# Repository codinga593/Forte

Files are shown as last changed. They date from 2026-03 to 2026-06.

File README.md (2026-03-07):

FORTE is a mid powered rocket with an estimated flight alitude of 137m initially, and a planned 1000m flight on a high powered motor later. 
It features a miniature onboard flight computer to verify data logging and live telemetry capabilties. 
The Flight computer has an inertial measurement unit and barometer to sense it's height and orientation. A LoRa Chip is placed onboard to stream data over 915 mHz to a ground station. 

The PCB is mainly for telemetry and datalogging, running custom firmware to achieve this. To get the PCB, you can send the gerber files to your manufacturer of choice, and buy components from online services such as LCSC, digikey or mouser. The rocket kit is available from LOC Precision and costs about $90.

This Rocket is my next step in my rocketry journey, allowing me to explore telemetry onboard rockets, efficient datalogging and building up to something more complex such as active control.

Render of Final PCB
Screenshot 2026-03-08 at 9 48 38 am

Model of Rocket
Screenshot 2026-03-08 at 9 41 17 am

Avionics Bay CAD
Screenshot 2026-03-08 at 9 33 35 am

## Bill of Materials (BOM)

| Designator | Part Name | Qty | Value / Part Number | Link |
|---|---|---|---|---|
| C14, C15, C16, C17, C18, C27, C28, C29, C30, C31, C35, C36 | Capacitor | 12 | 100 nF 0603 | https://www.digikey.com/en/products/detail/murata-electronics/GRM188R71C104KA01D |
| C13, C20, C21 | Capacitor | 3 | 1 µF 0603 | https://www.digikey.com/en/products/detail/murata-electronics/GRM188R61A105KA61D |
| C24, C25 | Capacitor | 2 | 2.2 µF 0603 | https://www.digikey.com/en/products/detail/murata-electronics/GRM188R61A225KE15 |
| C22, C23 | Capacitor | 2 | 10 pF 0603 | https://www.digikey.com/en/products/detail/murata-electronics/GRM1885C1H100JA01D |
| C34 | Capacitor | 1 | 22 µF 0603 | https://www.digikey.com/en/products/detail/murata-electronics/GRM188R60J226MEA0 |
| C26, C38, C39 | Capacitor | 3 | 100 nF 0603 | https://www.digikey.com/en/products/detail/murata-electronics/GRM188R71C104KA01D |
| R2, R3, R4, R8, R9, R10, R11, R12, R13, R14, R15, R18 | Resistor | 12 | 10 kΩ 0603 | https://www.digikey.com/en/products/detail/yageo/RC0603FR-0710KL |
| R16, R17 | Resistor | 2 | 0603 220Ω | https://www.digikey.com/en/products/detail/yageo/RC0603FR |
| U3 | Microcontroller | 1 | STM32F405RGT6 | https://www.digikey.com/en/products/detail/stmicroelectronics/STM32F405RGT6 |
| IC1 | SPI Flash Memory | 1 | W25Q128JVFIQ | https://www.digikey.com/en/products/detail/winbond-electronics/W25Q128JVFIQ |
| U2 | Barometric Pressure Sensor | 1 | MS5611-01BA | https://www.digikey.com/en/products/detail/te-connectivity/MS5611-01BA |
| U4 | GNSS Receiver | 1 | u-blox MAX-M10S | https://www.digikey.com/en/products/detail/u-blox/MAX-M10S-00B |
| U5 | USB ESD Protection | 1 | USBLC6-2SC6 | https://www.digikey.com/en/products/detail/stmicroelectronics/USBLC6-2SC6 |
| U13 | Buck Converter | 1 | TPS54525PWPR | https://www.digikey.com/en/products/detail/texas-instruments/TPS54525PWPR |
| Y2 | Crystal | 1 | 16 MHz SMD | https://www.digikey.com/en/products/detail/ecs-inc/ECS-160-20-33Q |
| J2 | RF Connector | 1 | U.FL-R-SMT-01 | https://www.digikey.com/en/products/detail/hirose-electric/U-FL-R-SMT-01 |
| J4 | USB-C Connector | 1 | USB4105-GF-A | https://www.digikey.com/en/products/detail/gct/USB4105-GF-A |
| TP1, TP2 | Test Point | 2 | PCB Test Pad | https://www.digikey.com/en/products/detail/keystone-electronics/5015 |
| SW2 | Slide Switch | 1 | SPDT (PCM12 style) | https://www.digikey.com/en/products/detail/c-k/PCM12SMTR |

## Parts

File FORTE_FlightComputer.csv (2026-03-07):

Id | Designator | Footprint | Quantity | Designation | Supplier and ref
1 | C27,C28,C16,C15,C18,C35,C17,C31,C14,C30,C36,C29 | C_0603_1608Metric | 12 | 100n
2 | IC1 | SOIC127P1032X264-16N | 1 | W25Q128JVFIQ
3 | J2 | HRS_U.FL-R-SMT_01_ | 1 | U.FL-R-SMT_01_
4 | R8,R3,R14,R10,R18,R9,R2,R15,R13,R4,R11,R12 | R_0603_1608Metric | 12 | 10k
5 | C20,C21,C13 | C_0603_1608Metric | 3 | 1u
6 | U5 | SOT-23-6 | 1 | USBLC6-2SC6
7 | C34 | C_0603_1608Metric | 1 | 22u
8 | C22,C23 | C_0603_1608Metric | 2 | 10pf
9 | U13 | PWP14_2P31X2P46_TEX | 1 | TPS54525PWPR
10 | U2 | LGA-8_3x5mm_P1.25mm | 1 | MS5611-01BA
11 | IC2 | 114993390 | 1 | 114993390
12 | R17,R16 | R_0603_1608Metric | 2 | R
13 | U4 | XCVR_MAX-M10S-00B | 1 | MAX-M10S-00B
14 | C24,C25 | C_0603_1608Metric | 2 | 2.2u
15 | Y2 | Crystal_SMD_3225-4Pin_3.2x2.5mm | 1 | 16Mhz
16 | U3 | LQFP-64_10x10mm_P0.5mm | 1 | STM32F405RGTx
17 | TP2,TP1 | TestPoint_Pad_1.5x1.5mm | 2 | TestPoint
18 | J4 | USB_C_Receptacle_GCT_USB4105-xx-A_16P_TopMnt_Horizontal | 1 | USB_C_Receptacle_USB2.0_16P
19 | C26,C39,C38 | C_0603_1608Metric | 3 | 100nf
20 | SW2 | SW_SPDT_PCM12 | 1 | SW_SPDT
21 | C19 | C_0603_1608Metric | 1 | 10n
22 | J5 | MOLEX_5025700893 | 1 | 5025700893
23 | J6 | AMASS_XT30PW-F_1x02_P2.50mm_Horizontal | 1 | Conn_01x02_Pin
24 | J3 | PinHeader_1x06_P2.54mm_Vertical | 1 | Conn_01x06_Pin
25 | C33 | C_0603_1608Metric | 1 | 10u
26 | U6 | XDCR_LSM6DSO32TR | 1 | LSM6DSO32TR
27 | L10 | WE-XHMA_6060 | 1 | 6.8 µH
28 | FB1 | FB_BLA31AG121SN4D | 1 | BLA31AG121SN4D
29 | R6,R7 | R_0603_1608Metric | 2 | 5k1
30 | C32 | C_0603_1608Metric | 1 | 10uF
31 | C37 | C_0603_1608Metric | 1 | 10uf

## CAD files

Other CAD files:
Avionics Bay.f3z

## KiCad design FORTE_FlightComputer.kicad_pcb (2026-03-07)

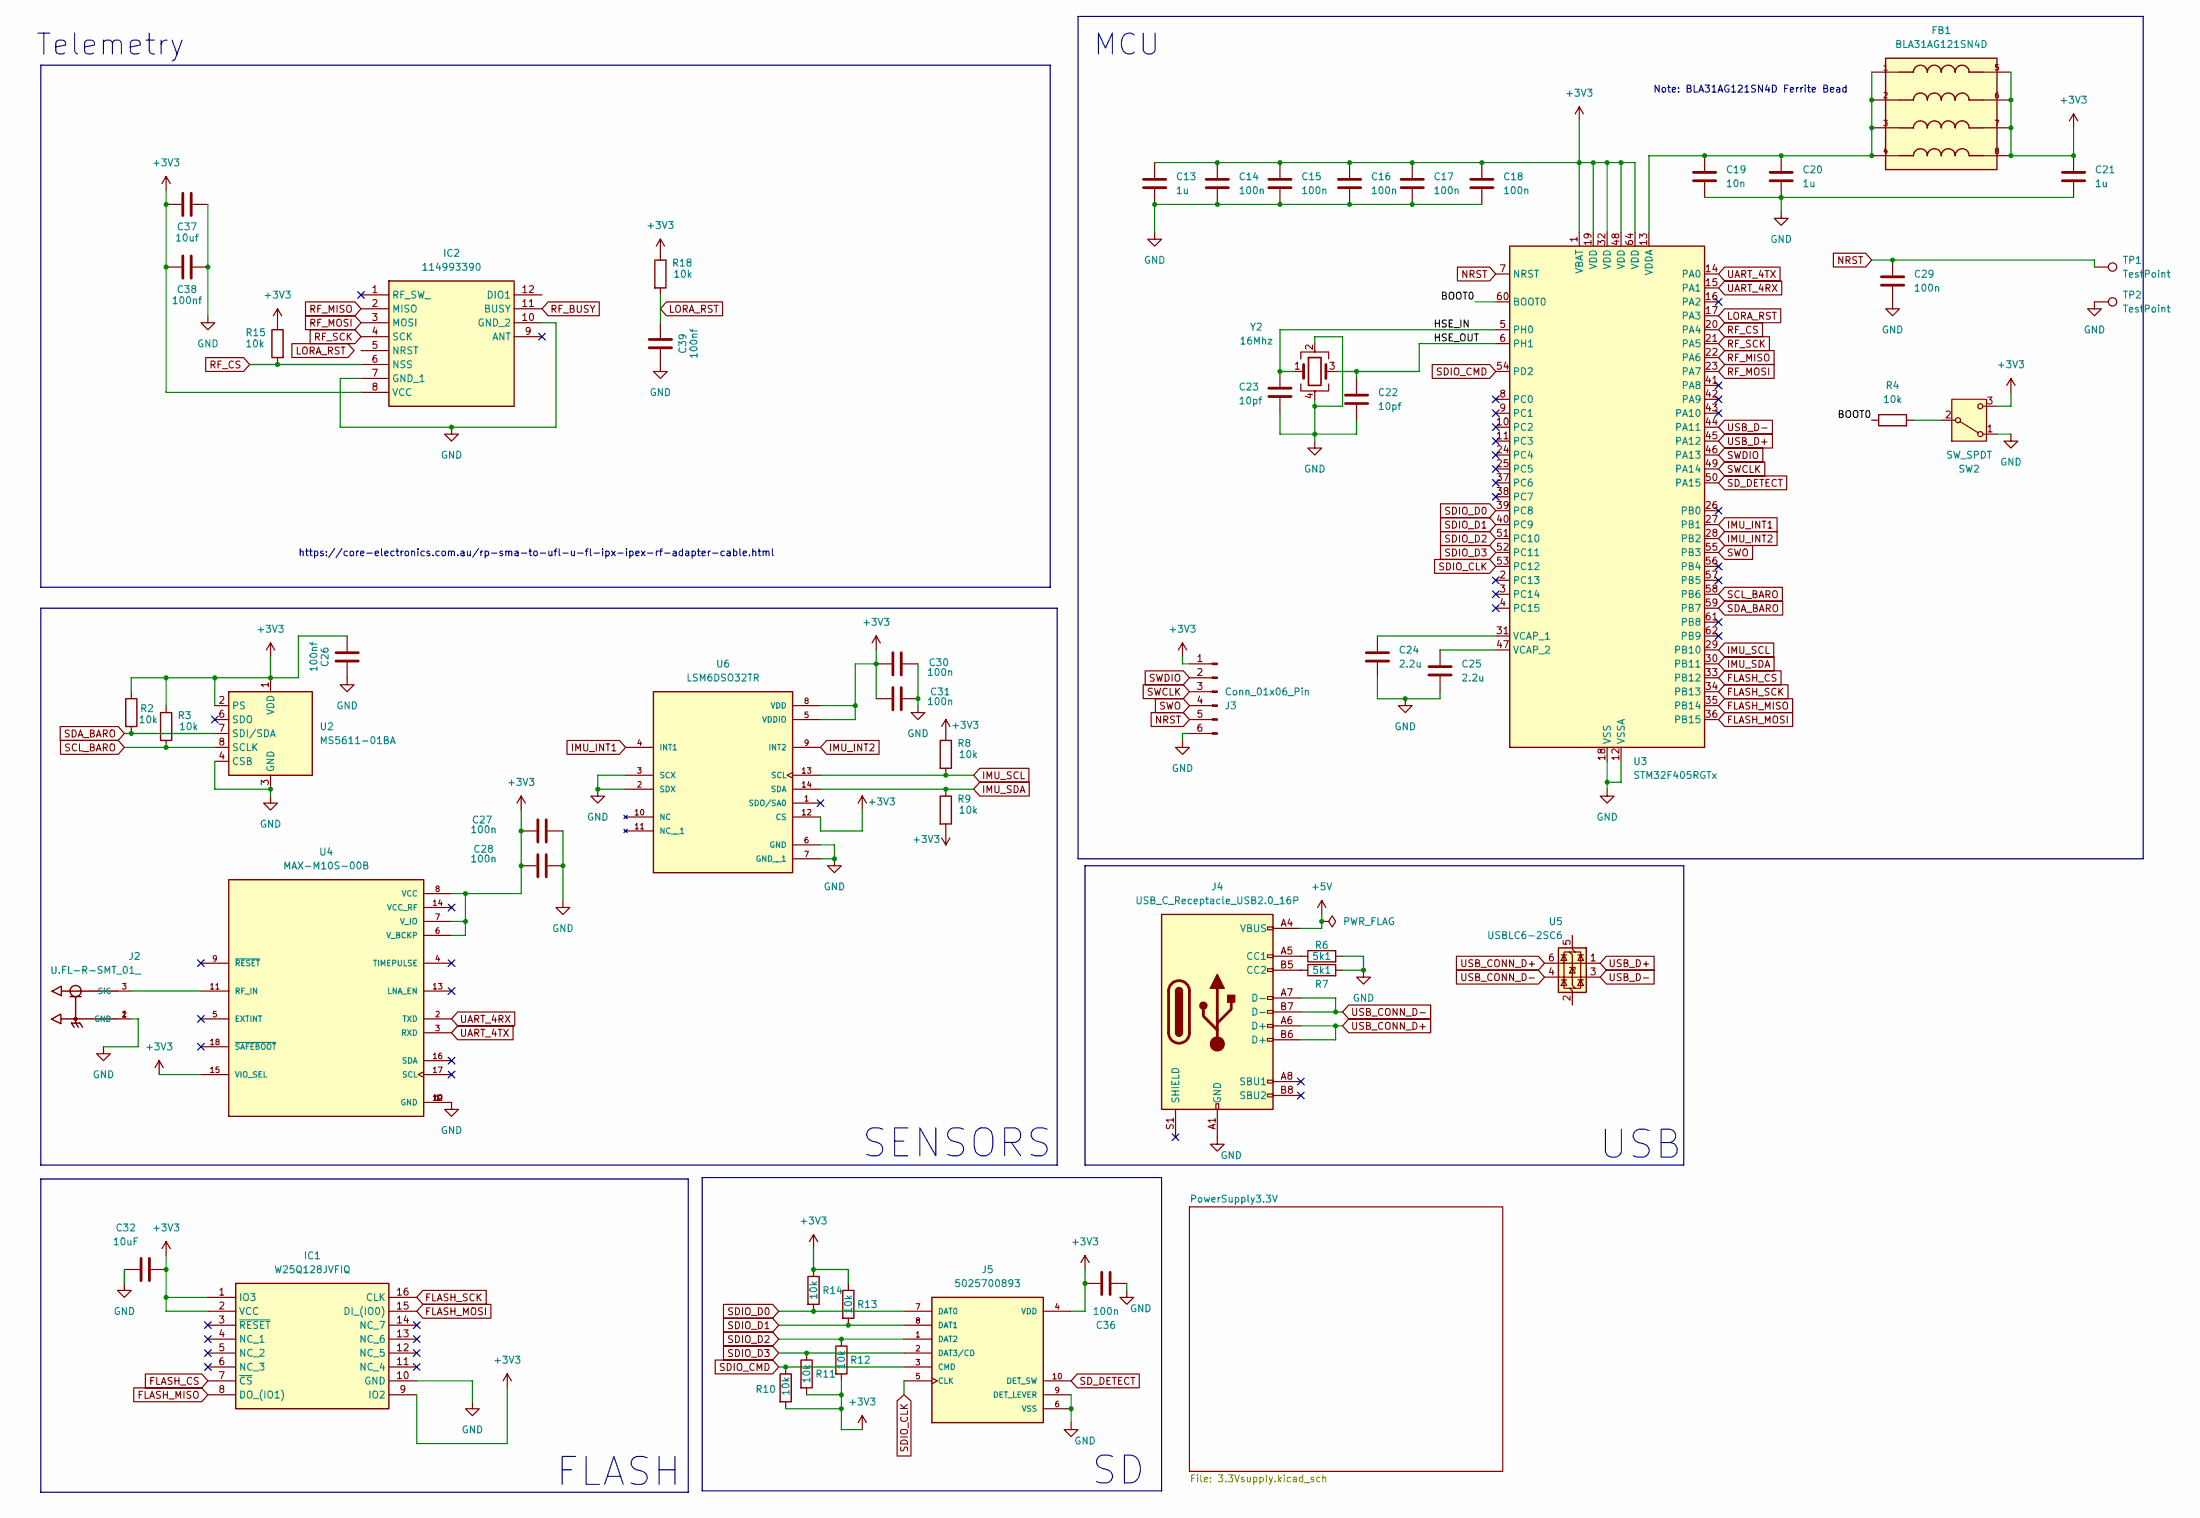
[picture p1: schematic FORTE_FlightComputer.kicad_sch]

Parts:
C13, C20, C21: 1u; C_0603_1608Metric
C14, C15, C16, C17, C18, C27, C28, C29, C30, C31, C36: 100n; C_0603_1608Metric
C19: 10n; C_0603_1608Metric
C22, C23: 10pf; C_0603_1608Metric
C24, C25: 2.2u; C_0603_1608Metric
C26, C38, C39: 100nf; C_0603_1608Metric
C32: 10uF; C_0603_1608Metric
C37: 10uf; C_0603_1608Metric
FB1: BLA31AG121SN4D; FB_BLA31AG121SN4D; PARTREV JENF243A–0008N-01
IC1: W25Q128JVFIQ; SOIC127P1032X264-16N; Mouser Part Number 454-W25Q128JVFIQ
IC2: 114993390; Mouser Part Number 713-114993390
J2: U.FL-R-SMT_01_; HRS_U.FL-R-SMT_01_
J3: Conn_01x06_Pin; PinHeader_1x06_P2.54mm_Vertical
J4: USB_C_Receptacle_USB2.0_16P; USB_C_Receptacle_GCT_USB4105-xx-A_16P_TopMnt_Horizontal
J5: 5025700893; MOLEX_5025700893
R2, R3, R4, R8, R9, R10, R11, R12, R13, R14, R15, R18: 10k; R_0603_1608Metric
R6, R7: 5k1; R_0603_1608Metric
SW2: SW_SPDT; SW_SPDT_PCM12
TP1, TP2: TestPoint; TestPoint_Pad_1.5x1.5mm
U2: MS5611-01BA; LGA-8_3x5mm_P1.25mm
U3: STM32F405RGTx; LQFP-64_10x10mm_P0.5mm
U4: MAX-M10S-00B; XCVR_MAX-M10S-00B; PARTREV C1
U5: USBLC6-2SC6; SOT-23-6
U6: LSM6DSO32TR; XDCR_LSM6DSO32TR; PARTREV 1
Y2: 16Mhz; Crystal_SMD_3225-4Pin_3.2x2.5mm

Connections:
+3V3: C13.1, C14.1, C15.1, C16.1, C17.1, C18.1, C21.1, C26.1, C27.1, C28.1, C30.1, C31.1, C32.2, C36.2, C37.1, C38.1, FB1.5, FB1.6, FB1.7, FB1.8, IC1.1 (IO3), IC1.2 (VCC), IC1.9 (IO2), IC2.8 (VCC), J3.1, J5.4 (VDD), R2.1, R3.1, R8.1, R9.2, R10.2, R11.2, R12.2, R13.1, R14.1, R15.1, R18.1, SW2.3 (C), U2.1 (VDD), U2.2 (PS), U3.1 (VBAT), U3.19 (VDD), U3.32 (VDD), U3.48 (VDD), U3.64 (VDD), U4.6 (V_BCKP), U4.7 (V_IO), U4.8 (VCC), U4.15 (VIO_SEL), U6.5 (VDDIO), U6.8 (VDD), U6.12 (CS); also elsewhere on the board
+5V: J4.A4 (VBUS), J4.A9 (VBUS), J4.B4 (VBUS), J4.B9 (VBUS)
/BOOT0: R4.1, U3.60 (BOOT0)
/HSE_IN: C23.1, U3.5 (PH0), Y2.1
/HSE_OUT: C22.1, U3.6 (PH1), Y2.3
FLASH_CS: IC1.7 (~CS), U3.33 (PB12)
FLASH_MISO: IC1.8 (DO_(IO1)), U3.35 (PB14)
FLASH_MOSI: IC1.15 (DI_(IO0)), U3.36 (PB15)
FLASH_SCK: IC1.16 (CLK), U3.34 (PB13)
GND: C13.2, C14.2, C15.2, C16.2, C17.2, C18.2, C19.2, C20.2, C21.2, C22.2, C23.2, C24.2, C25.2, C26.2, C27.2, C28.2, C29.2, C30.2, C31.2, C32.1, C36.1, C37.2, C38.2, C39.1, IC1.10 (GND), IC2.7 (GND_1), IC2.10 (GND_2), J2.1 (GND), J2.2 (GND), J3.6, J4.A1 (GND), J4.A12 (GND), J4.B1 (GND), J4.B12 (GND), J5.6 (VSS), J5.9 (DET_LEVER), R6.2, R7.2, SW2.1 (A), TP2.1, U2.3 (GND), U2.4 (CSB), U2.5 (CSB), U3.12 (VSSA), U3.18 (VSS), U3.63 (VSS), U4.1 (GND), U4.10 (GND), U4.12 (GND), U6.2 (SDX), U6.3 (SCX), U6.6 (GND), U6.7 (GND__1), Y2.2, Y2.4; also elsewhere on the board
IMU_INT1: U3.27 (PB1), U6.4 (INT1)
IMU_INT2: U3.28 (PB2), U6.9 (INT2)
IMU_SCL: R8.2, U3.29 (PB10), U6.13 (SCL)
IMU_SDA: R9.1, U3.30 (PB11), U6.14 (SDA)
LORA_RST: C39.2, R18.2, U3.17 (PA3)
NRST: C29.1, J3.5, TP1.1, U3.7 (NRST)
unnamed: J2.3 (SIG), U4.11 (RF_IN)
unnamed: J4.A5 (CC1), R6.1
unnamed: J4.B5 (CC2), R7.1
unnamed: R4.2, SW2.2 (B)
unnamed: C24.1, U3.31 (VCAP_1)
unnamed: C25.1, U3.47 (VCAP_2)
unnamed: C19.1, C20.1, FB1.1, FB1.2, FB1.3, FB1.4, U3.13 (VDDA)
RF_BUSY: IC2.11 (BUSY)
RF_CS: IC2.6 (NSS), R15.2, U3.20 (PA4)
RF_MISO: IC2.2 (MISO), U3.22 (PA6)
RF_MOSI: IC2.3 (MOSI), U3.23 (PA7)
RF_SCK: IC2.4 (SCK), U3.21 (PA5)
SCL_BARO: R3.2, U2.8 (SCLK), U3.58 (PB6)
SDA_BARO: R2.2, U2.7 (SDI/SDA), U3.59 (PB7)
SDIO_CLK: J5.5 (CLK), U3.53 (PC12)
SDIO_CMD: J5.3 (CMD), R10.1, U3.54 (PD2)
SDIO_D0: J5.7 (DAT0), R14.2, U3.39 (PC8)
SDIO_D1: J5.8 (DAT1), R13.2, U3.40 (PC9)
SDIO_D2: J5.1 (DAT2), R12.1, U3.51 (PC10)
SDIO_D3: J5.2 (DAT3/CD), R11.1, U3.52 (PC11)
SD_DETECT: J5.10 (DET_SW), U3.50 (PA15)
SWCLK: J3.3, U3.49 (PA14)
SWDIO: J3.2, U3.46 (PA13)
SWO: J3.4, U3.55 (PB3)
UART_4RX: U3.15 (PA1), U4.2 (TXD)
UART_4TX: U3.14 (PA0), U4.3 (RXD)
USB_CONN_D+: J4.A6 (D+), J4.B6 (D+), U5.6 (I/O1)
USB_CONN_D-: J4.A7 (D-), J4.B7 (D-), U5.4 (I/O2)
USB_D+: U3.45 (PA12), U5.1 (I/O1)
USB_D-: U3.44 (PA11), U5.3 (I/O2)

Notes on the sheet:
Note: BLA31AG121SN4D Ferrite Bead
FLASH
SENSORS
USB
MCU
https://core-electronics.com.au/rp-sma-to-ufl-u-fl-ipx-ipex-rf-adapter-cable.html
Telemetry

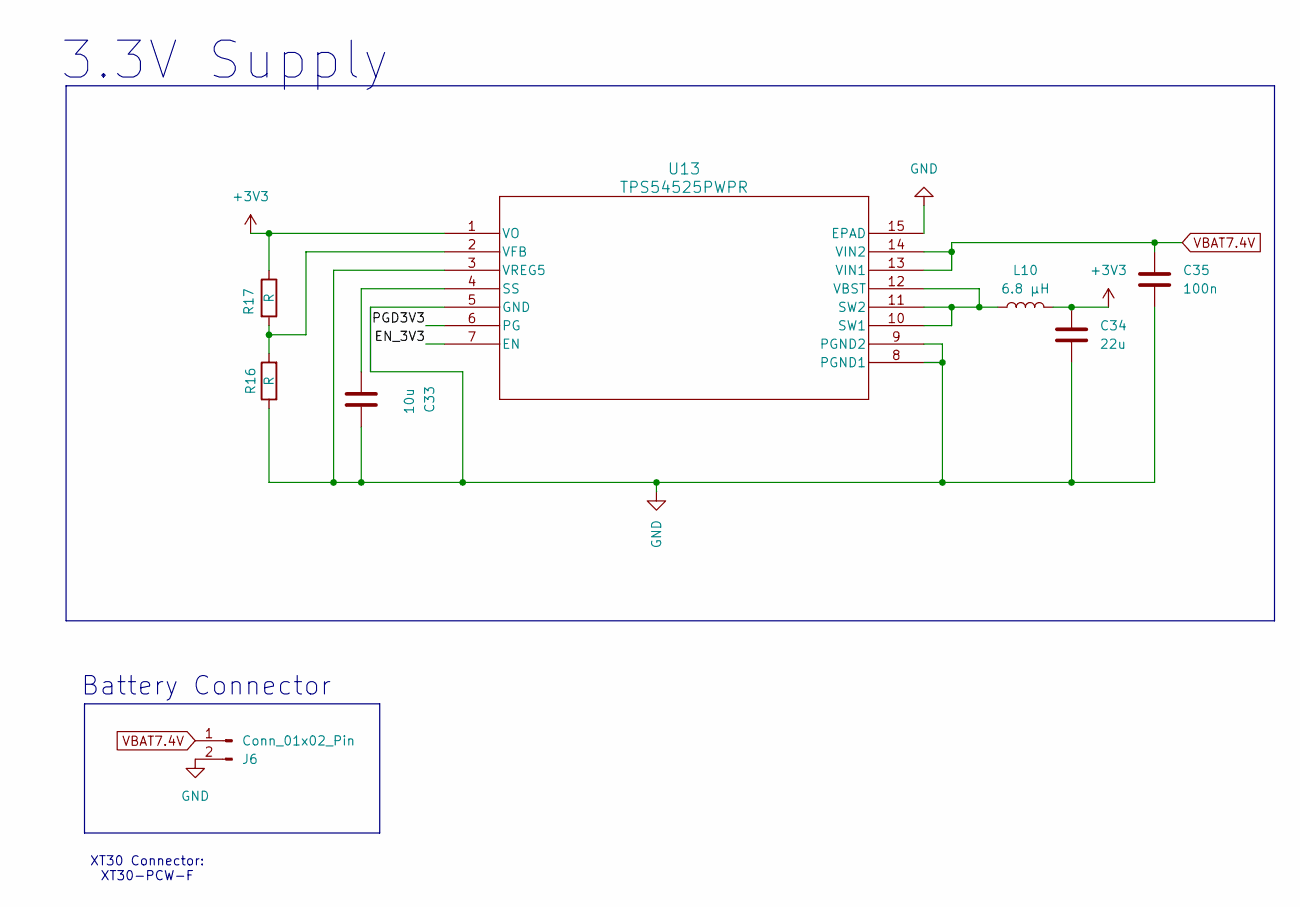
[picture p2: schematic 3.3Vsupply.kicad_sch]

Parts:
C33: 10u; C_0603_1608Metric
C34: 22u; C_0603_1608Metric
C35: 100n; C_0603_1608Metric
J6: Conn_01x02_Pin; AMASS_XT30PW-F_1x02_P2.50mm_Horizontal
L10: 6.8 µH; WE-XHMA_6060
R16, R17: R; R_0603_1608Metric
U13: TPS54525PWPR; PWP14_2P31X2P46_TEX

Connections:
+3V3: C34.1, L10.2, R17.1, U13.1 (VO); also elsewhere on the board
/PowerSupply3.3V/EN_3V3: U13.7 (EN)
/PowerSupply3.3V/PGD3V3: U13.6 (PG)
GND: C33.1, C34.2, C35.2, J6.2, R16.1, U13.3 (VREG5), U13.5 (GND), U13.8 (PGND1), U13.9 (PGND2), U13.15 (EPAD); also elsewhere on the board
unnamed: C33.2, U13.4 (SS)
unnamed: L10.1, U13.10 (SW1), U13.11 (SW2), U13.12 (VBST)
unnamed: R16.2, R17.2, U13.2 (VFB)
VBAT7.4V: C35.1, J6.1, U13.13 (VIN1), U13.14 (VIN2)

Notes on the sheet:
XT30 Connector: XT30-PCW-F
3.3V Supply
Battery Connector

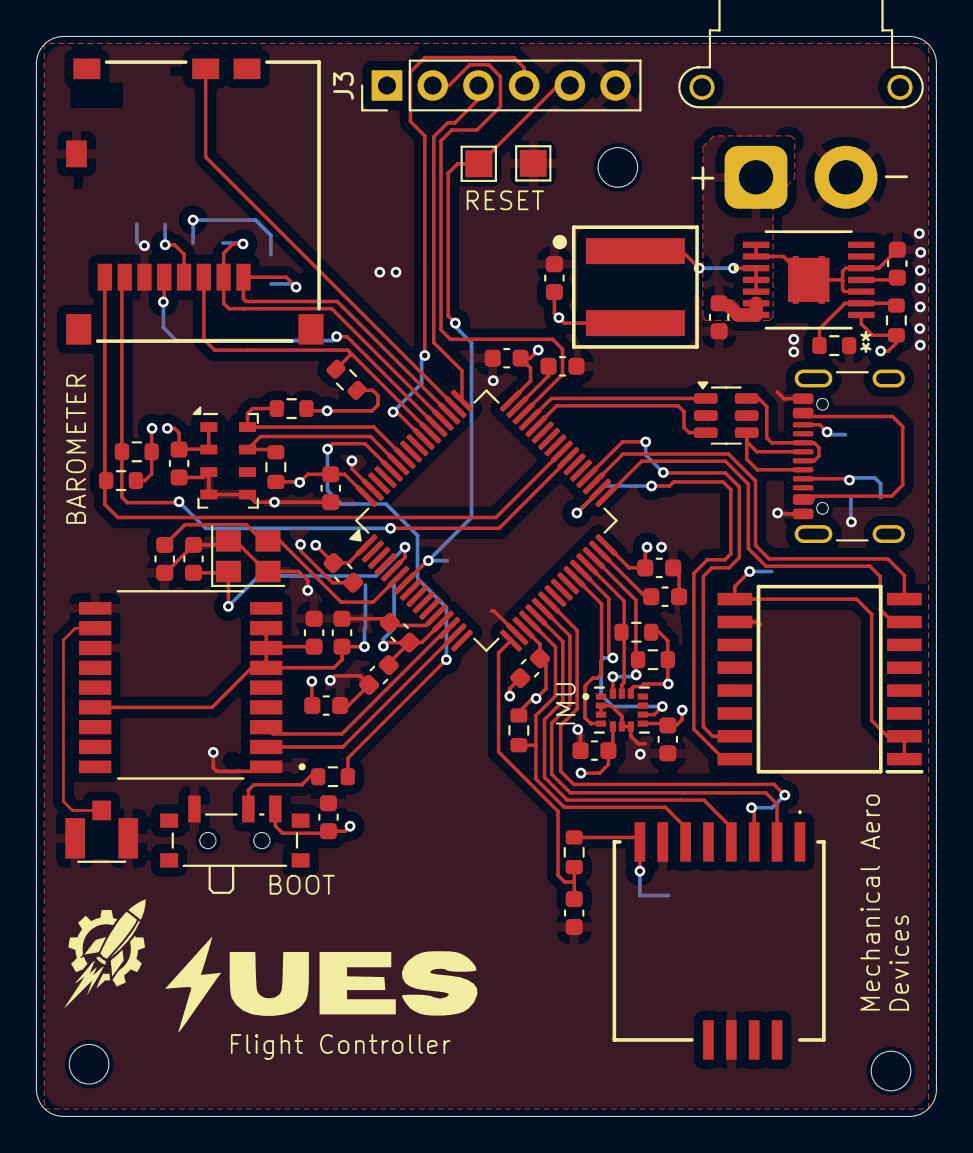
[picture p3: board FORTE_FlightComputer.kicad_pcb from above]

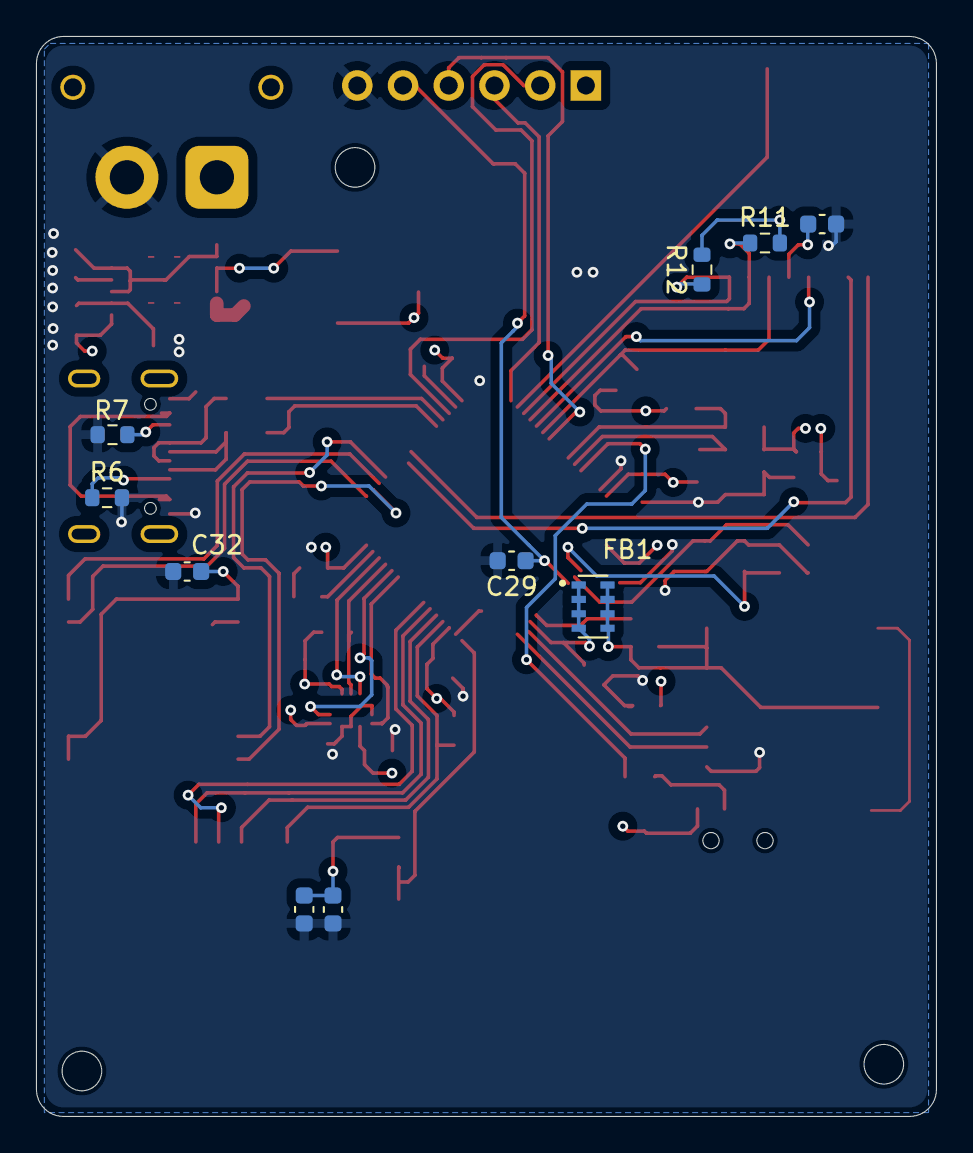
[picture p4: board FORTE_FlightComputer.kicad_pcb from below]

Board: 4 copper layers, 50.0 x 60.0 mm, 62 parts (10 on the bottom side), 49 nets.

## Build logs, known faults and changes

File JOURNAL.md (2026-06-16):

<!--
  This journal is auto generated by Hack Club Blueprint.
-->

# 3/2/2026 - Designed the Open Rocket File   

_Time spent: 5.0h_  

I modified the existing open rocket file for the FORTE rocket kit to ensure that the CP-CG ratio would work with my existing rocket motors. I ensure to add a mass component for my onboard flight computer that will be streaming live telemetry to the ground. The stability margin was 1.63 calibers, optimal for a mid powered rocket.

Open Rocket is a program that is used to design and test model rockets, and this by designing my rocket in this software first, I verified flight stability and ejection conditions, ensuring that the flight would be successful in real life.  Screenshot 2026-03-02 at 5.51.05 pm

# 3/22/2026 5 PM - Defined overall architecture and component selection  

_Time spent: 6.0h_  

I defined the overall architecture of the flight computer, determining how all subsystems would interact during operation. This included selecting the STM32F405RGT6 as the primary microcontroller due to its processing capability and peripheral support. I chose and justified the sensor suite, including the LSM6DS03 IMU for orientation, a u blox M10S GPS for positional data, a barometer for altitude estimation (MS5611-01BA), and an SX1262 chip for LoRa telemetry. I also designed the high level signal flow between components and planned the power distribution strategy.

I also read all the data sheets to ensure that my routing would be correct while designing the PCB. This would ensure that when put in the rocket, all the components work correctly.
Screenshot 2026-03-22 at 5.54.58 pm
![Screenshot 2026-03-22 at 5.54.46 pm](/user-attachments/blobs/proxy/eyJfcmFpbHMiOnsiZGF0YSI6MTI1MzM3LCJwdXIiOiJibGScreenshot 2026-03-22 at 5.58.59 pm
9iX2lkIn19--d947096d5df8abaf37092fcf0b31c908f92ed48b/Screenshot%202026-03-22%20at%205.54.46%E2%80%AFpm.png)

# 3/22/2026 6:03 PM - Schematic Design & Integration  

_Time spent: 4.5h_  

Screenshot 2026-03-22 at 6.04.15 pm
I developed the full electrical schematic for the flight computer, integrating all selected components into a cohesive design. This involved implementing power regulation circuits, MCU clock circuitry, and communication interfaces such as SPI, I2C, and UART for sensor and module connectivity. I ensured correct pin mapping and peripheral allocation on the microcontroller to align with intended firmware functionality. Additionally, I verified connectivity and performed basic electrical validation to ensure the design was logically and electrically sound.

The schematic is the basis for the PCB Design and will ensure that the component connections are correct and sound when fitted inside the avionics bay of the rocket. 

Screenshot 2026-03-22 at 6.02.29 pm
Screenshot 2026-03-22 at 6.02.17 pmScreenshot 2026-03-22 at 6.02.37 pmScreenshot 2026-03-22 at 6.02.45 pm

# 3/22/2026 6:07 PM - PCB Stackup & Component Placement  

_Time spent: 3.1h_  

I established the PCB stackup and defined design rules appropriate for a compact, high performance avionics board. Components were placed to optimise signal integrity and physical layout, including minimising trace lengths between the MCU and critical sensors such as the IMU. RF components were positioned to reduce interference, and connectors and mounting holes were aligned with planned avionics bay integration. This stage focused on creating a clean and efficient physical layout before routing began.

I experimented with various layouts, shifting and moving component but ultimately settled on the following layout.
Screenshot 2026-03-22 at 6.07.10 pm
Note: All Copper Layers are turned off in the image

# 3/22/2026 6:11 PM - Routed Important signals  

_Time spent: 5.5h_  

I routed the critical high speed and timing sensitive signals on the PCB, including SPI connections between the MCU and IMU and UART lines for the GPS module. I ensured short, direct trace paths and avoided unnecessary vias in order to preserve signal integrity. Initial power traces were also routed, ensuring stable delivery to key components. This stage prioritised the most sensitive connections before completing the rest of the board routing. 

By doing the important traces first, this ensured functionality of the PCB once placed in demanding conditions as these connections were nearly guaranteed to work.


# 3/22/2026 6:13 PM - Reviewed EMI and general PCB   

_Time spent: 3.0h_  

I reviewed the overall functionality and routing of the PCB, making sure that decoupling capacitors were used near all major integrated circuits. A consistent grounding strategy was applied using ground planes on every layer to minimise electrical noise and improve system stability. Voltage regulation circuits were finalised, and attention was given to ensuring reliable operation under expected load conditions. This stage ensured that the board would function reliably in a high vibration rocket environment during the flight. 


# 3/22/2026 6:16 PM - Final Changes to PCB  

_Time spent: 6.5h_  

I refined the PCB design over three iterations, incorporating feedback and resolving identified issues. A key improvement was replacing a custom SX1262 RF frontend with a prebuilt LoRa module to increase reliability and reduce integration risk. I resolved design rule check (DRC) errors, improved routing clarity, and finalised the silkscreen for readability and assembly. The design was then prepared for manufacturing, ensuring it met all necessary fabrication requirements (JLCPCB as Fab). 

The feedback I received from others proved invaluable as I changed the push button for BOOT to two test pads which have to be shorted, ensuring that the high vibration and mechanical stress of a rocket flight don't accidentally switch the FC into boot mode. 
Screenshot 2026-03-22 at 6.15.41 pm
Screenshot 2026-03-22 at 6.15.47 pm

# 3/22/2026 6:20 PM - Wrote Sensor Drivers  

_Time spent: 7.0h_  

I developed custom firmware drivers for the onboard sensors, including the LSM6DS03 IMU, barometer, and GPS module. This involved implementing communication protocols such as SPI, I2C, and UART, and ensuring accurate data acquisition from each device. This stage established the foundation for reliable sensor input during flight.

While the bulk of coding has been done in C in the STM32 Cube IDE, a portion of the coding (testing and debugging) remains to be done once the PCB's are received which will ensure that these programs will work reliably during the rocket flight. 

Screenshot 2026-03-22 at 6.19.30 pm
Screenshot 2026-03-22 at 6.19.20 pmScreenshot 2026-03-22 at 6.19.12 pmScreenshot 2026-03-22 at 6.19.05 pmScreenshot 2026-03-22 at 6.18.47 pm

# 3/22/2026 6:25 PM - Wrote the Implementation Part of the Sensor Drivers  

_Time spent: 6.3h_  

I implemented the sensor drivers by developing the low-level code responsible for direct communication between the microcontroller and each onboard device. This involved writing the .cpp source files to handle SPI, I2C, and UART transactions, configuring sensor registers, and managing data acquisition for the IMU, barometer, and GPS modules. I ensured reliable and efficient data transfer by structuring the code to minimise latency and handle potential communication errors. This formed a stable foundation for higher level flight control and data logging.
Screenshot 2026-03-22 at 6.23.44 pmScreenshot 2026-03-22 at 6.23.58 pmScreenshot 2026-03-22 at 6.24.06 pmScreenshot 2026-03-22 at 6.24.11 pmScreenshot 2026-03-22 at 6.24.16 pm

# 3/22/2026 6:27 PM - Final Flight Code  

_Time spent: 4.0h_  

The Final flight code for datalogging onboard my rocket. It included the prior sensor drivers. It was a simple state machine with liftoff detection and sent the state estimate of the rocket over LoRa and logged to the flash,SD. This included information such as velocity, gps lat, long, ax, ay, az and much more. Screenshot 2026-03-22 at 6.27.29 pm

# 3/25/2026 - Final Avionics Bay Design  

_Time spent: 3.0h_  

I designed the avionics bay in fusion 360 to house the flight computer. This will be integrated into the main rocket as seen in the second screenshot. The Bay features a sled to hold the PCB which is connected to the forward and aft bulkheads by m6 threaded rods. The bay also has a LiPo holder to house the battery. 
Screenshot 2026-03-25 at 9.09.36 pm 

Screenshot 2026-03-25 at 9.12.34 pm  

# 4/18/2026 - PCB Assembly  

_Time spent: 6.5h_  

I got the PCB and parts from digikey and element14. I used the stencil to spread solder paste evenly across the pads. I then carefully placed each part and IC across the PCB, before bringing it to a hotplate for reflow. I heated the hotplate to 200 degrees celsius, melting the solder paste and fixing the ICS in place. I had to replace the MCU a few times to get a good connection to the pads. 

However, after checking with a multimeter there were multiple solder bridges between the pins of the MCU and a short was present between 3v3 and gnd. To fix this, I will use a hot air gun to melt the solder and put some flux during my next soldering session. 

Most of the soldering is done with some resistors being left and some rework being needed.  


# 5/3/2026 7:25 PM - Soldering  

_Time spent: 2.0h_  

Attempted to fix the solder bridges on the MCU, and got most of them. However, there are some still remaining after soldering. 

I will attempt to fix these in my next soldering sessions  

# 5/3/2026 7:27 PM - More soldering  

_Time spent: 4.0h_  

I went heavy with the flux during this soldering sessions, attempting to fix the bridges. I also soldered the rest of the capacitors and resistors which arrived from aliexpress. Overall, soldering is mostly complete apart from 2 bridges and the back. WhatsApp Image 2026-05-03 at 19.07.23

# 5/3/2026 7:32 PM - Assembly of Kit  

_Time spent: 6.0h_  

I dry fitted the parts of the rocket together to test the fit. I had to sand some of the centering rings to ensure that they would fit. After that, I mixed some epoxy and glued on the centering rings as per the instructions provided. They did fit nicely. I then attached the bolt onto the forward centering ring, attaching the braided shock cord but I'll sand them  bit more. This should ensure the rocket doesnt tear upon deployment.WhatsApp Image 2026-05-03 at 19.32.11 (1)
WhatsApp Image 2026-05-03 at 19.32.11WhatsApp Image 2026-05-03 at 19.32.11 (2)WhatsApp Image 2026-05-03 at 19.32.11 (3)

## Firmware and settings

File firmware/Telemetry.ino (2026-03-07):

#include <Arduino.h>
#include <math.h>
#include <SPI.h>
#include <Wire.h>

#include "baro_ms5611.h"
#include "config_pins.h"
#include "data_types.h"
#include "flash_w25q128.h"
#include "gps_parser.h"
#include "imu_lsm6dso32.h"
#include "lora_sx1262.h"

#if __has_include(<SD.h>)
#include <SD.h>
#define HAS_SD_LIB 1
#else
#define HAS_SD_LIB 0
#endif

namespace {
LSM6DSO32 imu(IMU_I2C_BUS, IMU_I2C_ADDR);
MS5611 baro(BARO_I2C_BUS, MS5611_I2C_ADDR);
W25Q128 flashLog(FLASH_SPI_BUS, FLASH_CS_PIN);
Sx1262Radio lora(
  LORA_SPI_BUS,
  LORA_NSS_PIN,
  LORA_BUSY_PIN,
  LORA_DIO1_PIN,
  LORA_RESET_PIN
);
NmeaParser gps;

FlightSample sample {};
uint32_t flightStartMs = 0;
uint32_t lastLoopMs = 0;
uint32_t lastLoraTxMs = 0;
bool armed = false;
bool inFlight = false;
bool landed = false;
bool sdDumpDone = false;

float seaLevelPressureMbar = 1013.25f;
float prevAltitudeM = 0.0f;
float verticalSpeedMps = 0.0f;
float verticalAccelMps2 = 0.0f;
float prevVerticalSpeedMps = 0.0f;

uint16_t checksum16(const uint8_t *data, size_t len) {
  uint32_t sum = 0;
  for (size_t i = 0; i < len; i++) {
    sum += data[i];
  }
  return static_cast<uint16_t>(sum & 0xFFFFu);
}

float pressureToAltitudeM(float pressureMbar) {
  if (pressureMbar <= 0.0f) {
    return 0.0f;
  }
  return 44330.0f * (1.0f - powf(pressureMbar / seaLevelPressureMbar, 0.19029495f));
}

void readGpsStream() {
  while (GPS_UART.available()) {
    const char c = static_cast<char>(GPS_UART.read());
    gps.feed(c);
  }
}

bool detectLiftOff(const FlightSample &s) {
  const bool accelTrigger = fabsf(s.ax_g) > 2.2f || fabsf(s.ay_g) > 2.2f || fabsf(s.az_g) > 2.2f;
  const bool climbTrigger = s.altitude_m > 15.0f && verticalSpeedMps > 5.0f;
  return accelTrigger || climbTrigger;
}

bool detectLanding(const FlightSample &s, uint32_t nowMs) {
  if (!inFlight) {
    return false;
  }

  const bool nearGround = s.altitude_m < 8.0f;
  const bool lowVSpeed = fabsf(verticalSpeedMps) < 0.6f;
  const bool lowAccel = fabsf(s.ax_g) < 0.35f && fabsf(s.ay_g) < 0.35f && fabsf(s.az_g - 1.0f) < 0.35f;
  const bool minFlightTime = (nowMs - flightStartMs) > MIN_FLIGHT_TIME_MS;

  return minFlightTime && nearGround && lowVSpeed && lowAccel;
}

void fillSample(uint32_t nowMs) {
  sample.magic = SAMPLE_MAGIC;
  sample.ms = nowMs;
  sample.state = landed ? FlightState::LANDED : (inFlight ? FlightState::ASCENT_DESCENT : FlightState::ARMED_IDLE);

  imu.readAccelGyro(
    sample.ax_g, sample.ay_g, sample.az_g,
    sample.gx_dps, sample.gy_dps, sample.gz_dps
  );

  sample.temperature_c = baro.readTemperatureC();
  sample.pressure_mbar = baro.readPressureMbar();
  sample.altitude_m = pressureToAltitudeM(sample.pressure_mbar);

  const float dt = (lastLoopMs == 0) ? (LOOP_PERIOD_MS / 1000.0f) : (nowMs - lastLoopMs) / 1000.0f;
  verticalSpeedMps = (dt > 0.001f) ? ((sample.altitude_m - prevAltitudeM) / dt) : 0.0f;
  verticalAccelMps2 = (dt > 0.001f) ? ((verticalSpeedMps - prevVerticalSpeedMps) / dt) : 0.0f;
  prevAltitudeM = sample.altitude_m;
  prevVerticalSpeedMps = verticalSpeedMps;

  sample.vspeed_mps = verticalSpeedMps;
  sample.vaccel_mps2 = verticalAccelMps2;

  gps.copyTo(sample.gps);

  sample.checksum = checksum16(
    reinterpret_cast<const uint8_t *>(&sample),
    sizeof(FlightSample) - sizeof(sample.checksum)
  );
}

void sendLoraStatus(uint32_t nowMs) {
  if ((nowMs - lastLoraTxMs) < LORA_TX_INTERVAL_MS) {
    return;
  }
  lastLoraTxMs = nowMs;

  char packet[180];
  snprintf(
    packet,
    sizeof(packet),
    "$TLM,%lu,%u,%.2f,%.2f,%.2f,%.2f,%.2f,%.2f,%.2f,%.2f,%d,%.6f,%.6f,%.1f,%u",
    static_cast<unsigned long>(sample.ms),
    static_cast<unsigned int>(sample.state),
    sample.altitude_m,
    sample.vspeed_mps,
    sample.ax_g,
    sample.ay_g,
    sample.az_g,
    sample.gx_dps,
    sample.gy_dps,
    sample.gz_dps,
    sample.gps.fix,
    sample.gps.lat_deg,
    sample.gps.lon_deg,
    sample.gps.alt_m,
    sample.gps.sats
  );
  lora.transmit(packet);
}

void writeSampleToFlash() {
  flashLog.append(
    reinterpret_cast<const uint8_t *>(&sample),
    sizeof(sample)
  );
}

void dumpFlashToSdCard() {
  if (sdDumpDone) {
    return;
  }
#if HAS_SD_LIB
  if (!SD.begin()) {
    Serial.println("SD init failed, will retry");
    return;
  }

  File f = SD.open("/flight_log.csv", FILE_WRITE);
  if (!f) {
    Serial.println("SD open failed");
    return;
  }

  f.println(
    "ms,state,ax_g,ay_g,az_g,gx_dps,gy_dps,gz_dps,temp_c,pressure_mbar,alt_m,vspeed_mps,vaccel_mps2,"
    "gps_fix,lat,lon,gps_alt_m,gps_speed_mps,gps_course_deg,sats"
  );

  FlightSample r {};
  uint32_t addr = 0;
  const uint32_t end = flashLog.bytesWritten();
  while (addr + sizeof(FlightSample) <= end) {
    flashLog.read(addr, reinterpret_cast<uint8_t *>(&r), sizeof(r));
    addr += sizeof(r);
    const uint16_t cs = checksum16(
      reinterpret_cast<const uint8_t *>(&r),
      sizeof(r) - sizeof(r.checksum)
    );
    if (r.magic != SAMPLE_MAGIC || cs != r.checksum) {
      continue;
    }
    char line[240];
    snprintf(
      line, sizeof(line),
      "%lu,%u,%.4f,%.4f,%.4f,%.3f,%.3f,%.3f,%.2f,%.2f,%.2f,%.3f,%.3f,%d,%.7f,%.7f,%.2f,%.2f,%.2f,%u",
      static_cast<unsigned long>(r.ms),
      static_cast<unsigned int>(r.state),
      r.ax_g, r.ay_g, r.az_g,
      r.gx_dps, r.gy_dps, r.gz_dps,
      r.temperature_c, r.pressure_mbar, r.altitude_m,
      r.vspeed_mps, r.vaccel_mps2,
      r.gps.fix, r.gps.lat_deg, r.gps.lon_deg,
      r.gps.alt_m, r.gps.speed_mps, r.gps.course_deg,
      r.gps.sats
    );
    f.println(line);
  }

  f.flush();
  f.close();
  sdDumpDone = true;
  Serial.println("Flash->SD transfer complete");
#else
  Serial.println("SD library not found in core; cannot export yet");
#endif
}
}  // namespace

void setup() {
  Serial.begin(DEBUG_BAUD);
  delay(250);
  Serial.println("Telemetry firmware boot");

  BARO_I2C_BUS.begin();
  IMU_I2C_BUS.begin();
  GPS_UART.begin(GPS_BAUD);

  if (!imu.begin()) {
    Serial.println("IMU init failed");
  }
  if (!baro.begin()) {
    Serial.println("MS5611 init failed");
  }
  if (!flashLog.begin()) {
    Serial.println("Flash init failed");
  }
  if (!lora.begin()) {
    Serial.println("LoRa init failed");
  }

  const float p0 = baro.readPressureMbar();
  if (p0 > 100.0f && p0 < 1200.0f) {
    seaLevelPressureMbar = p0;
  }
  Serial.print("Sea-level baseline mbar: ");
  Serial.println(seaLevelPressureMbar, 2);
}

void loop() {
  const uint32_t nowMs = millis();
  readGpsStream();

  if ((nowMs - lastLoopMs) < LOOP_PERIOD_MS) {
    return;
  }

  fillSample(nowMs);

  if (!armed && (nowMs > 3000 || sample.gps.fix)) {
    armed = true;
  }
  if (!inFlight && armed && detectLiftOff(sample)) {
    inFlight = true;
    flightStartMs = nowMs;
    Serial.println("Liftoff detected");
  }
  if (!landed && detectLanding(sample, nowMs)) {
    landed = true;
    Serial.println("Landing detected");
  }

  writeSampleToFlash();
  sendLoraStatus(nowMs);

  if (landed) {
    dumpFlashToSdCard();
  }

  lastLoopMs = nowMs;
}

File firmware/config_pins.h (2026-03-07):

#pragma once

#include <Arduino.h>
#include <SPI.h>
#include <Wire.h>

// ===== Bus assignment =====
// STM32F405 typically exposes Wire (I2C1) and Wire1 (I2C2) in STM32Duino.
#if defined(WIRE_INTERFACES_COUNT) && (WIRE_INTERFACES_COUNT > 1)
#define IMU_I2C_BUS Wire1
#else
#define IMU_I2C_BUS Wire
#endif

#define BARO_I2C_BUS Wire

// GPS on UART4 RX path (module TX -> MCU RX). In STM32Duino, Serial4 maps to UART4.
#define GPS_UART Serial4

// SPI buses (adjust if your board variant names differ).
#define FLASH_SPI_BUS SPI
#define LORA_SPI_BUS SPI

// ===== Addresses =====
static constexpr uint8_t IMU_I2C_ADDR = 0x6A;
static constexpr uint8_t MS5611_I2C_ADDR = 0x77;

// ===== W25Q128 pins =====
// Replace these with your PCB net mapping.
static constexpr uint8_t FLASH_CS_PIN = PB0;

// ===== SX1262 pins =====
// Replace these with your PCB net mapping.
static constexpr uint8_t LORA_NSS_PIN = PB12;
static constexpr uint8_t LORA_BUSY_PIN = PB1;
static constexpr uint8_t LORA_DIO1_PIN = PB2;
static constexpr uint8_t LORA_RESET_PIN = PB10;

// ===== Runtime timing =====
static constexpr uint32_t DEBUG_BAUD = 115200;
static constexpr uint32_t GPS_BAUD = 9600;
static constexpr uint32_t LOOP_PERIOD_MS = 20;       // 50Hz sample loop
static constexpr uint32_t LORA_TX_INTERVAL_MS = 200; // 5Hz telemetry
static constexpr uint32_t MIN_FLIGHT_TIME_MS = 6000;
static constexpr float LORA_FREQ_MHZ = 915.0f;       // US915 default
